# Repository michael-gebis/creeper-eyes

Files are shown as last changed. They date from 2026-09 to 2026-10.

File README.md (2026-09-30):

# Frankenstein Head with Animated Eyes

Twin animated eyes for Jose Aveleira's 3D-printed
[Frankenstein head with animated eyes](https://www.printables.com/model/620191-frankenstein-head-with-animated-eyes),
driven by an ESP32 and two 1.5" OLED panels.

The eyes wander, blink and dilate on their own, and keep doing it with nothing
plugged in but power. Everything past that is optional.

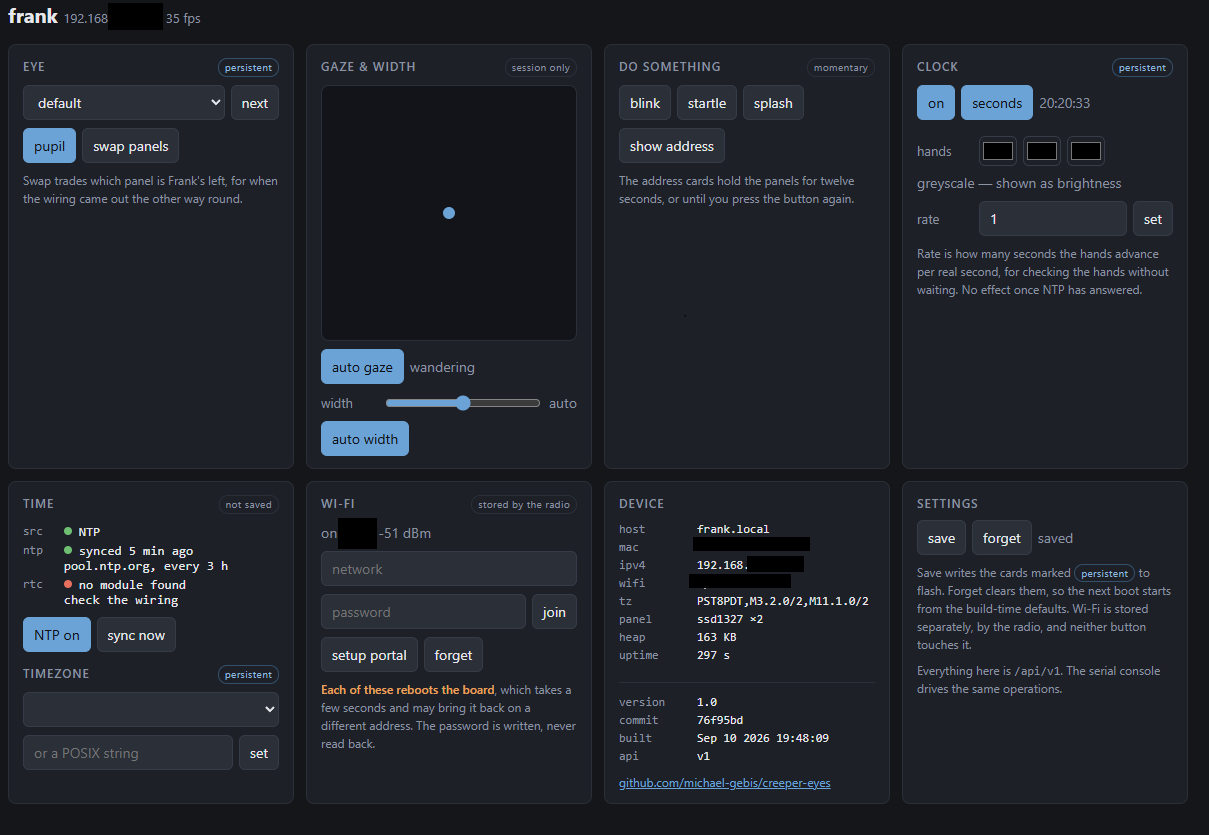
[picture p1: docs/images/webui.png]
The control page


## What it does

- **Twenty-five eye designs** — [see them all](docs/EYES.md). One is built in; any other can be
  loaded from a file on the control page, [no rebuild needed](docs/EYE_FILES.md)
- **Watches the room on its own**: wandering gaze, autonomous blinking, pupils
  that dilate
- **Takes direction** from a web page, a serial console or a REST API, so you
  can aim the gaze or fire a startle effect without opening the head
- **Tells the time**, with an analogue clock drawn in the iris
- **Sleeps at night**, so it is not staring at 3am
- **Dims to suit the room**, fading between levels, and switches right off —
  [brightness](docs/BRIGHTNESS.md)
- **Sets itself up from a code on the eye** — point a phone at it and it
  joins the head's network and opens the setup page, with nothing typed
- **Updates over WiFi**, so a sealed head never needs opening again
- **Runs on a generic ESP32** and either colour or greyscale panels

Two panels, one dev board, fourteen wires. If you would rather not have the
wires, there is [a circuit board](hardware/README.md) for it.

## What to buy

### ESP32 board

Any **classic ESP32** (ESP-WROOM-32 module, Xtensa dual core) with 4 MB flash.

> **Not** an ESP32-**S2**, **S3**, **C3** or **C6**. Those are different
> architectures and will not run this build. If your board shows up as USB
> vendor ID `303A`, it is one of those. A classic ESP32 uses a separate
> USB-serial chip — CH340 (`1A86`) or CP210x (`10C4`).

Known good: the 30-pin **DOIT ESP32 DevKit V1**, sold under a dozen names with
"NodeMCU", "ESP32S" and "Type-C" in the title. Roughly $5 each in three-packs.
Either USB-serial chip is fine; CH340 may need a driver on Windows.

### Displays — read this part carefully

Waveshare sells **two different 1.5" 128×128 OLED modules** with nearly
identical names and **identical 7-pin headers**. You cannot tell them apart by
wiring, and the wrong one shows white static.

| Product | Controller | Display | Build to use |
| :--- | :--- | :--- | :--- |
| **1.5inch RGB OLED Module** | SSD1351 | 65K colour | `esp32dev` |
| **1.5inch OLED Module** | SSD1327 | 16 greys | `gray` |

Buy **two**. Either works, and the grayscale panels run faster.

Which to get depends on the eyes you want. The artwork was drawn in colour,
and **some designs do not survive the conversion** — anything carrying its
detail in hue rather than in brightness comes out flat. The newt is the worst
of them: its greens and golds land on much the same grey. Others lose nothing
worth having; the default eye in particular looks every bit as good in
sixteen greys as it does in colour.

[docs/EYES.md](docs/EYES.md) renders all 25 designs both ways, side by side,
which is the quickest way to decide.

Both are 3.3 V / 5 V tolerant and need no level shifting.

### Everything else

- Breadboard and male-to-female jumper wires (14 connections)
- USB-C cable — this also carries the serial console
- The printed parts and hardware from the
  [Printables model](https://www.printables.com/model/620191-frankenstein-head-with-animated-eyes)

A plain USB port powers everything comfortably: two panels and the ESP32,
WiFi and all, sit well inside the 500 mA a port supplies.

## Wiring

Six signals are shared by both panels; only chip select differs. Left and
right below are **Frank's own**, so facing him, his right eye is the one on
your left.

| Signal | DevKit pin | Frank's right (your left) | Frank's left (your right) |
| :----- | :--- | :--- | :--- |
| VCC | `3V3` | VCC | VCC |
| GND | `GND` | GND | GND |
| DIN | `D18` | DIN | DIN |
| CLK | `D5` | CLK | CLK |
| DC | `D33` | DC  | DC  |
| RST | `D27` | RST | RST |
| CS | `D15` / `D4` | CS ← `D15` | CS ← `D4` |

> **Use `3V3`, never `VIN`.** ESP32 GPIOs are 3.3 V and not 5 V tolerant.

Module silkscreens vary between sellers — `DIN` may be labelled `SDA`, `SI` or
`MOSI`; `CLK` may be `SCL`, `SCK` or `D0`. Match by position, not by letters.

**Full details, assembly order and troubleshooting: [docs/WIRING.md](docs/WIRING.md).**

Optional, and compiled out by default: a **battery-backed clock**, four more
wires onto two otherwise idle pins — [docs/WIRING_RTC.md](docs/WIRING_RTC.md).

### Or a circuit board instead of the jumpers

The same fourteen wires exist as a carrier board in
[hardware/](hardware/README.md): the DevKit plugs into a socket, each eye gets
its own header, and the SPI bus is copper rather than Dupont leads — which
matters mostly because nothing can work loose inside a sealed head. About $10
for five boards.

> **Rev A is tested and works**: a DevKit on one drives two colour panels and a
> DS3231, the clock on jumpers because its header suits a different module
> from the one in use. **Rev B**, which changes that header, is **untested**:
> it passes KiCad's checks, and no board has been made.

## Build and flash

This is a [PlatformIO](https://platformio.org/) project. No Arduino IDE needed,
and nothing to install by hand beyond PlatformIO itself — the Xtensa toolchain,
the ESP32 Arduino core and the Adafruit libraries all download on the first
build.

**New to PlatformIO?** Install the
[PlatformIO IDE extension for VS Code](https://docs.platformio.org/en/latest/integration/ide/vscode.html).
It is the same two steps on Windows, macOS and Linux — install VS Code, then
install the extension — and its Quick Start walks you through building a
blinking LED before you come back here. The extension includes the command
line this page uses, so nothing below is closed off by starting there.

**Happier in a terminal?** Install PlatformIO Core on its own. The
[installation methods](https://docs.platformio.org/en/latest/core/installation/methods/index.html)
page covers all three systems; the short version is:

```sh
uv tool install platformio       # or: pipx install platformio
```

### Environments

| Environment | Builds | Use for |
| :--- | :----- | :--- |
| `esp32dev` | Eyes, SSD1351 colour | **Default.** Waveshare 1.5inch RGB OLED |
| `gray` | Eyes, SSD1327 grayscale | Waveshare 1.5inch OLED |
| `displaytest` | Solid-colour fills, SSD1351 | Bring-up and fault isolation |
| `probe1327` | Raw SSD1327 init, no library | Identifying an unknown panel |
| `esp32dev_rtc` / `gray_rtc_open` | Eyes plus a battery-backed clock | With a [DS3231 fitted](docs/WIRING_RTC.md) |
| `gray_rtc` | The same, with authentication on | A head left on a network. Needs credentials in `secrets.h` |
| `esp32dev_local` / `gray_local` | Eyes only, no networking | A head with no WiFi — about 695 KB smaller |
| `gray_rtc_ota` / `esp32dev_rtc_ota` | The RTC builds, flashed over WiFi | **Use these** to update an RTC or authenticated head |
| `esp32dev_ota` / `gray_ota` | The plain builds, flashed over WiFi | Updating a sealed head. Using one on an RTC board flashes the RTC and auth away |
| `rtc_probe` | Raw I²C scan and DS3231 read | Bringing up an RTC module |
| `qrtest` / `qrtest_rgb` | QR codes on the panels, grey / colour, no network | Measuring what a phone can read — [Codes on the eyes](docs/QR.md) |

`gray_rtc` is the only environment that requires anything of you before it
will build: `AUTH_USER`, `AUTH_PASS`, `AUTH_TOKEN_VALUE` and `OTA_PASSWORD` in
`include/secrets.h`. It stops with an error naming them rather than producing
an open device. Use `gray_rtc_open` to skip that.

### Commands

```sh
pio run                              # build the default (colour) environment
pio run -e gray -t upload            # build and flash the grayscale build
pio run -e gray -t upload -t monitor # ...and open the console
pio device monitor                   # console only
pio device list                      # find the serial port
```

If the port is picked wrongly, pin it in `platformio.ini` with
`upload_port = COM5` (or `/dev/ttyUSB0`).

## Where to go next

This page gets you a working head. Everything else has a page of its own.

| | |
| :-- | :-- |
| [Wiring](docs/WIRING.md) | Every wire, in order, with what goes wrong |
| [The eyes](docs/EYES.md) | The gallery, choosing designs, the pupil, the startup cards, a panel fitted the wrong way |
| [Eye files](docs/EYE_FILES.md) | One more design, loaded from the control page without a rebuild |
| [Driving it](docs/CONTROL.md) | Web page, serial console, REST API |
| [Networking](docs/NETWORK.md) | Joining WiFi, changing it later, updating over the air |
| [Codes on the eyes](docs/QR.md) | Setup and address codes, and what a phone can really read off a panel |
| [Keeping time](docs/TIME.md) | Time servers, the clock face, running without a network |
| [Brightness](docs/BRIGHTNESS.md) | The dimmer: curves, fades, matching two panels |
| [Sleep mode](docs/SLEEP.md) | Dark panels overnight |
| [Configuring](docs/CONFIG.md) | Every build option, and what gets saved |
| [Locking it down](docs/SECURITY.md) | Passwords, and why there is no HTTPS |
| [A circuit board](hardware/README.md) | The wiring as a PCB — rev A tested, rev B not yet made |
| [Testing](docs/TESTING.md) | The test suite, the soak harness, the tools |
| [Frame rate](docs/FRAME_RATE.md) | How the eyes went from 19 frames a second to 51 on colour, and from 33 to 75 on greyscale |

And two pages that are neither instructions nor reference, but a record of
being wrong in public: [why a 35-byte request took 50 ms](docs/HTTP_LATENCY.md)
and [the battery-backed clock](docs/WIRING_RTC.md).

## Troubleshooting

| Symptom | Cause |
| :--- | :---- |
| **Both panels show white static** | Wrong controller. You have SSD1327 panels and built `esp32dev`, or vice versa. Confirm with `pio run -e probe1327 -t upload -t monitor` — if the panels respond to that, they are SSD1327; build `gray`. |
| Both panels dark | Power, or `D27` (RST) not connected. Check 3V3 and GND at the module pins. |
| One panel dark | That panel's `CS` wire. Everything else is shared, so a shared fault would take out both. |
| Flicker or speckle | Bus integrity. Shorten the `CLK` and `DIN` jumpers, or lower the bus speed: `SSD1351_SPI_HZ` for colour, `SSD1327_SPI_HZ` for greyscale. |
| Garbled serial output | `DEBUG_BAUD` and `monitor_speed` disagree, or a CH340 clone struggling above 115200. |
| Board resets when a panel is connected | Brownout. Use a powered hub or feed 5 V to `VIN`. |
| Board will not boot | Something on `D12`. Held high at reset it stops the ESP32 starting. No eye signal uses it. |
| The web page lags, or an update fails | Almost certainly the radio. Check the signal on the Wi-Fi card — the page says what the number means. Every delay and every failed update measured on this project traced back to packet loss, not to the firmware. `uv run tools/test_api.py --host frank.local --decompose 200` takes the guesswork out of it. |

Frame rate is **not** a useful signal for whether panels are connected — the
SPI writes happen either way, so the rate is the same with nothing attached.

For bring-up, `displaytest` drives each panel alone with solid fills at a
deliberately slow 2 MHz, which separates wiring faults from rendering faults.

## Credits

**The head itself is [Jose Aveleira's](https://www.printables.com/@JoseAveleira_1373378)**
— [Frankenstein head with animated eyes](https://www.printables.com/model/620191-frankenstein-head-with-animated-eyes)
on Printables. None of this has anywhere to live without it.

Firmware lineage, oldest first:

- **[Adafruit Uncanny Eyes](https://learn.adafruit.com/animated-electronic-eyes)** — Phil Burgess / Paint Your Dragon, for Adafruit Industries. The rendering engine and the eye artwork. SPI FIFO insight from Paul Stoffregen's `ILI9341_t3`; concept inspired by David Boccabella (Marcwolf).
- **Laurent Moll**, 2018 — [Uncanny Eyes costume](https://www.hackster.io/projects/376a13/), dual-display ESP32 work.
- **[bitcldr/creeper-eyes](https://github.com/bitcldr/creeper-eyes)** — the PlatformIO project this forks from.
- **[TeensyEyes](https://github.com/chrismiller/TeensyEyes)** — Chris Miller. MIT. 23 of the 25 eye designs are converted from its artwork by [`tools/gen_eyes.py`](tools/gen_eyes.py).
- This fork — generic ESP32 support, grayscale panels, console, splash, diagnostics,
  networking, the control page and API, eye files, the dimmer and the carrier board.

Three bugs fixed here also affect the upstream colour build: an out-of-range
eyelid index that put a teardrop artifact at one eye's edge, a shared reset
line that wiped the first panel's initialisation while the second started, and
a chip-select constant that selected the wrong panel during init.

MIT licensed — see [LICENSE](LICENSE).

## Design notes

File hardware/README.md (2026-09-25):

# A circuit board for Frank

The breadboard and its fourteen jumper wires, as a printed circuit board: a
carrier that the ESP32 DevKit plugs into, with a header for each eye and one
for the optional clock, and the SPI bus in copper instead of Dupont leads.

> **Rev A is tested and works.** A DevKit plugged into one drives two colour
> panels, with a DS3231 on jumpers — its header suits the ZS-042, not the
> module in use, which is what rev B changes — and without C1. Under long,
> heavy test load on a single USB-C supply it browned out now and then; see
> [Frame rate](../docs/FRAME_RATE.md#brownouts-and-the-cpu-at-160-mhz). Fit C1.
>
> **Rev B is untested.** It passes KiCad's checks — electrical rules,
> schematic against board, design rules — and no board has been made.

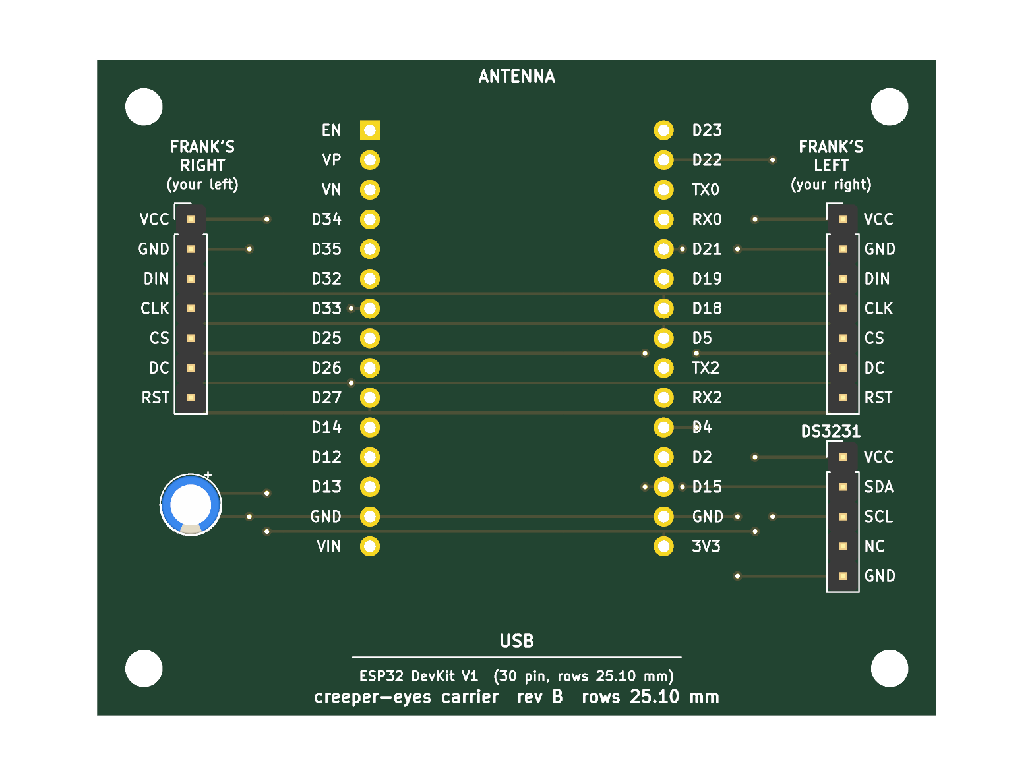
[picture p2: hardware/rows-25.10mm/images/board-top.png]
The board, top side


## What it is

There are no discrete electronics in this project. The whole thing is three
off-the-shelf modules and the wires between them:

- an ESP32 DevKit V1 (30-pin, 2.54 mm headers)
- two Waveshare 1.5" OLED panels, which share an identical 7-pin header
- optionally, a DS3231 module

So the board is a **carrier**: a socket for the DevKit, a 7-pin header for
each eye, a 5-pin header for the RTC, and the shared SPI bus routed between
them in copper. One capacitor, because the panels' boost converters draw in
bursts and it costs nothing. No active parts, nothing surface-mount, nothing
to calculate. Its job is to replace the breadboard with something that cannot
come loose inside a sealed head.

The wiring is exactly [WIRING.md](../docs/WIRING.md) and
[WIRING_RTC.md](../docs/WIRING_RTC.md):

| Signal | DevKit pin | Goes to |
| :----- | :--- | :--- |
| 3V3 | `3V3` | both panels, RTC, C1 |
| GND | `GND` | both panels, RTC, C1 |
| DIN | `D18` | both panels |
| CLK | `D5` | both panels |
| DC | `D33` | both panels |
| RST | `D27` | both panels |
| CS | `D15` | Frank's right panel (J3, your left) |
| CS | `D4` | Frank's left panel (J4, your right) |
| SDA | `D21` | RTC |
| SCL | `D22` | RTC |

72 × 56 mm, two layers, four M3 mounting holes. The DevKit plugs in with its
USB connector towards the bottom edge and its antenna end flush with the top
edge — the antenna section overhangs by about half a millimetre, and there
is no copper anywhere near it in any case. Every socket pin is labelled with the
DevKit's own name for it, and each eye connector says whose eye it is in
both senses, so a board sitting on the bench answers the question the wiring
guide spends a page on.

The panels connect by cable — a 7-wire Dupont lead or a JST-XH pigtail onto
each header — because they live in the head's eye sockets, not on the board.
The RTC header takes the five-pin "DS3231 mini" module sold for the Raspberry
Pi, which plugs straight onto it: `VCC SDA SCL NC GND` from top to bottom,
matching the module's own `+ D C NC -`, with GND on the bottom pin. Any other
module goes on by four wires to the labelled pins.

## Revisions

**Rev B**, current, untested: J5, the RTC header, is five pins in the order of the
DS3231 mini module (`VCC SDA SCL NC GND`, rows 12–16) instead of six in the
ZS-042's (`32K SQW SCL SDA VCC GND`, rows 12–17). SCL keeps its route; SDA,
VCC and GND each come in on a different row. Nothing else moved.

**Rev A**, the first order, tested and working: the mini module does not plug
onto J5. Wire it
by name instead — four jumpers, module `+`→`VCC`, `D`→`SDA`, `C`→`SCL`,
`-`→`GND` — and leave J5's `32K` and `SQW` empty. Power off first: the
firmware only looks for the RTC at boot.

## What it costs

| | Five boards | Per board |
| :-- | :-- | :-- |
| JLCPCB or PCBWay, 2-layer, 72 × 56 mm | ~$2 fabrication, $2–5 slow shipping (~$20 by courier if impatient) | under $2 |
| Two 1×15 female headers, 2.54 mm — the DevKit socket | ~$1 | |
| Two 1×7 and one 1×5 male pin headers, 2.54 mm | ~$1 | |
| C1, electrolytic, 5 mm diameter, 2 mm lead pitch: 10 µF works, but take the largest that comes in a 5 mm can, typically 22 or 47 µF | pennies | |

**About $10 for five boards, all in**, and one to two weeks. The DevKit and
the displays you already own plug into it.

The other tier — an integrated board with the ESP32-WROOM module soldered
down, USB-C, a CH340 and a regulator, assembled at the fab — comes to $8–15 a
board in small quantities plus setup fees, and buys nothing over the $5 DevKit
except a slimmer profile and the loss of "unplug it and swap it". Not worth
it. This is a carrier board.

## Two boards, because there are two DevKits

Along each row the pins are on 2.54 mm centres on every board — that is the
header strip itself, and nobody gets it wrong. The distance *between* the two
rows is the clone maker's own choice, and it varies. So the design is one and
the boards are two, in directories named for the number:

| Directory | Row pitch | For |
| :-- | :-- | :-- |
| `rows-25.10mm/` | 25.10 mm | The author's DevKit, a 30-pin "DevKit V1" clone, measured |
| `rows-25.4mm/` | 25.4 mm (1.0") | The DOIT reference design and clones that follow it |

Each holds its own KiCad project, a `gerbers/creeper-eyes-rows-…-gerbers.zip`
to upload, and renders. The pitch is printed on both sides of the board, so
five of each can sit in a drawer without confusion.

## Before ordering: two things to check against your DevKit

Both are things a datasheet cannot settle, because "ESP32 DevKit V1" is a
name a dozen factories use.

1. **The row pitch.** Measure across both rows of pins with calipers, at
   the base of the pins where they enter the plastic rather than at the
   tips, which are often toed in. Take the outside-to-outside and the
   inside-to-inside readings: their average is the centre-to-centre pitch,
   and their difference should be one pin width (~0.64 mm), which tells you
   the measurement is sound. The author's board read 25.72 and 24.48, so
   25.10. Order the variant that matches; if neither does, add a line to
   `VARIANTS` in `gen_board.py` and regenerate (below). Half the board moves
   with it; nothing needs redrawing.
2. **The pinout.** Hold the DevKit with the USB connector towards you,
   components up. The left row should read `EN VP VN D34 D35 D32 D33 D25 D26
   D27 D14 D12 D13 GND VIN` top to bottom, and the right row `D23 D22 TX0 RX0
   D21 D19 D18 D5 TX2 RX2 D4 D2 D15 GND 3V3`. That is what the board's
   silkscreen says beside each socket pin, so a mismatch is a matter of
   holding the two next to each other. If a pin differs, `DEVKIT_LEFT` and
   `DEVKIT_RIGHT` in `gen_board.py` are where to say so.

Then two things worth knowing that are not risks: the pads are square for
pin 1 of every connector, and C1's footprint carries a `+` mark on the
silkscreen — the longer lead of the capacitor goes there.

## Ordering

Upload the zip from the matching variant's `gerbers/` directory to
[JLCPCB](https://jlcpcb.com) or [PCBWay](https://www.pcbway.com). The defaults are right: 2 layers, 1.6 mm,
HASL, any colour, quantity 5. Nothing on the board comes near a design rule —
the narrowest anything gets is 0.25 mm tracks and about 0.3 mm of clearance,
against minimums of 0.127.

Solder the two 15-pin sockets first, using the DevKit itself as a jig to keep
them parallel: plug the sockets onto the DevKit, drop the assembly into the
board, solder, unplug. Then the pin headers, then C1.

## How it was made, and how to change it

The board is generated by a script rather than drawn, because the one
dimension that has to be measured moves half the layout.

Both scripts run with the Python *inside* KiCad, not the system one, because
the layout is built through KiCad's own `pcbnew` module. Where that lives:

| | |
| :-- | :-- |
| Windows | `%LOCALAPPDATA%\Programs\KiCad\<version>\bin\python.exe` |
| macOS | `/Applications/KiCad/KiCad.app/Contents/Frameworks/Python.framework/Versions/Current/bin/python3` |
| Linux | the system `python3`, with KiCad's packages installed |

```sh
"$KICAD_PYTHON" hardware/gen_board.py     # writes every variant
"$KICAD_PYTHON" hardware/make_outputs.py  # checks and exports each
```

Either takes a pitch as an argument to do just one: `gen_board.py 25.4`.

Needs [KiCad](https://www.kicad.org/) 9 or later — the author used 10.
`gen_board.py` holds the netlist as one table and the routing as a list of
coordinates on a 2.54 mm grid, with everything right of the DevKit's left row
placed relative to the pitch; `make_outputs.py` runs the electrical rule
check, compares the schematic's netlist with the board's pad by pad, runs the
design rule check with schematic parity, and only then exports the Gerbers
and the renders. All three pass clean for both variants at the moment.

Editing in KiCad directly also works — it is an ordinary project — but a
regeneration will overwrite it, so a change worth keeping belongs in the
script.

The DevKit's footprint and the three symbols with meaningful pin names live in
each variant's `.pretty/` directory and `.kicad_sym` file, which its library
tables point at.

## Not on the board

Kept off deliberately, and cheap to add if there is ever a reason:

- a header breaking out the unused pins (`D23`, `D25`, `D26`, `D32`, `D34`,
  `D35`, …) for sensors. Not `D19`: the firmware hands it to the SPI
  peripheral as MISO in `SPI.begin(SCLK_PIN, MISO_PIN, MOSI_PIN)`, and
  although nothing is ever read back — the panels are write-only — the
  peripheral is attached to the pin all the same. Passing `-1` there instead
  would genuinely free it, and is the change to make before breaking it out.
- a photocell, which upstream Uncanny Eyes uses to drive dilation. A light
  sensor for the [dimmer](../docs/BRIGHTNESS.md) is on the
  [TODO list](../TODO.md#a-light-sensor-for-automatic-brightness), and the
  unused `D34`, `D35`, `VP` and `VN` are where it would go
- a ground pour — at 8 MHz on a 7 cm board, with the breadboard already
  working, it would be decoration

## Files

| | |
| :-- | :-- |
| `gen_board.py` | The design, as a script. Edit this. |
| `make_outputs.py` | Checks, Gerbers, renders |
| `rows-25.10mm/`, `rows-25.4mm/` | One directory per DevKit row pitch, each containing: |
| `  creeper-eyes-rows-…mm.kicad_pro` / `.kicad_sch` / `.kicad_pcb` | The KiCad project the script writes |
| `  creeper-eyes-rows-…mm.pretty/`, `.kicad_sym` | Project footprint and symbol libraries |
| `  gerbers/creeper-eyes-rows-…mm-gerbers.zip` | What the fab wants |
| `  images/` | Renders of both sides, and the schematic as a PDF |

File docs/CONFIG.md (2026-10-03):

# Configuring the firmware

Two kinds of setting, and it matters which is which.

**Build options** are compile-time: they decide what is in the firmware at
all, and changing one means a rebuild. Every switch is `#ifndef`-guarded, so
it can be overridden from `platformio.ini` without editing a header — with the
exception of the pin numbers, noted below.

**Saved settings** are runtime: the eye design, the timezone, the clock
colours. They live in flash, survive a reboot, and are changed from the
control page or the console.

## Build options

Compile-time switches. Most live in [`src/config.h`](../src/config.h); the ones
inherited from upstream are still declared in `src/main.cpp`, next to the
rendering code they belong to. Either way each is `#ifndef`-guarded, so any of
them can be overridden from `build_flags` in `platformio.ini` without editing
a source file — which is how the `gray` environment sets `USE_SSD1327`.

A few settings are PlatformIO's rather than the firmware's, and live in
`platformio.ini` itself, commented there: the partition table
(`board_build.partitions`, see [Eye files](EYE_FILES.md#where-the-room-came-from)),
and the flash at 80 MHz on four data lines (`board_build.f_flash`,
`board_build.flash_mode`) instead of the board definition's 40 MHz on two, which
roughly halved the time to draw an eye. Both only reach a board by a USB flash:
the partition table is written only by one, and the flash speed is set by the
bootloader, which is too. The CPU runs at 160 MHz rather than 240
(`board_build.f_cpu`), which saves enough current to matter. With
`OVERLAP_SEND` colour frames wait on the SPI bus, not the CPU, so it costs them
two frames a second; greyscale frames wait on the drawing and pay more, about a
quarter — see [Frame rate](FRAME_RATE.md#brownouts-and-the-cpu-at-160-mhz).
That is only the speed a board starts at: one with the supply for it can be
set to 240 without a rebuild, and keeps it as a
[saved setting](#remembering-settings).

Two groups are **not** guarded and cannot be overridden this way. A few
names are not settings at all: `CONTROLLABLE`, `OTA_AUTH` and
`FIRMWARE_COMMIT` are computed from others, `DIM_GAMMA_MIN` and
`DIM_GAMMA_MAX` are fixed limits, and `FAVICON_FRANK` and `FAVICON_EYES` are
the two values `FAVICON` chooses between. And the **pin numbers** in
[`src/main.cpp`](../src/main.cpp) (`DISPLAY_DC`, `DISPLAY_RESET`,
`SELECT_L_PIN`, `SELECT_R_PIN`, `MOSI_PIN`, `MISO_PIN`, `SCLK_PIN`) are plain
`#define`s: `-DDISPLAY_DC=…` is a macro
redefinition, not an override, so those are edited in place. They are wiring,
not preference — change them only if you wire differently, and update
[docs/WIRING.md](WIRING.md) to match.

| Option | Default | Effect |
| :----- | :--- | :----- |
| `USE_SSD1327` | `0` | Selects the grayscale panel driver. Set by the `gray` environment via `build_flags`, not edited by hand. |
| `COMMANDS` | `1` | Serial console and BOOT-button toggle. `0` compiles both out; the REST API still works, so a network build stays fully controllable. |
| `DEBUG` | `1` | Serial diagnostics and the LED heartbeat, which toggles once a second. `0` saves ~2 KB. |
| `DEBUG_BAUD` | `115200` | Console speed. **Must match `monitor_speed`** in `platformio.ini`. |
| `DEBUG_LED_PIN` | `2` | On-board LED used for the heartbeat. |
| `STARTUP_SPLASH` | `1` | Panel name cards at boot. `0` boots straight into the eyes. |
| `SPLASH_SECONDS` | `5` | How long the splash counts down. |
| `BOOT_BUTTON_PIN` | `0` | Button that cycles eye designs; held, the factory reset. |
| `SSD1327_SPI_HZ` | `8000000` | Grayscale bus speed. Lower it if long jumpers cause flicker. |
| `SSD1351_SPI_HZ` | `16000000` | Colour bus speed. A colour frame is four times the data of a greyscale one, so sending an eye is most of a colour frame: 33 ms at the library's 8 MHz, 18 ms at 16. The SSD1351 is rated to 20 MHz, which speckled one panel on the carrier board. Lower it if long jumpers speckle the image. |
| `RAM_TABLES` | `1` | Keep the current design's polar map and iris, 45 KB, in RAM rather than flash. Drawing reads both out of order, so from flash they miss the cache: an eye took 6.2 ms to draw from flash and 4.5 ms from RAM. `0` gives the RAM back. |
| `OVERLAP_SEND` | `1` | Send each eye's frame from the ESP32's other core while the render loop draws the next, so a frame takes as long as the longer of the two instead of both together: 41 fps to 53 on colour, and 55 to 101 on greyscale, both at 240 MHz. At the default 160 MHz they come to 51 and 75. Costs a second frame buffer, 32 KB on colour and 8 KB on greyscale. See [Frame rate](FRAME_RATE.md). |
| `STARTLE_WINDUP_MS` | `1400` | Slow constrict before the startle jolt. |
| `CLOCK` | `1` | Analogue clock face. `0` compiles it out. |
| `CLOCK_*_LEN` / `CLOCK_*_HW` | — | Hand lengths and half-widths, in pixels from the iris centre. |
| `CLOCK_*_COLOR` | `0x000000` | Starting hand colours, changeable at runtime with `clock color`. |
| `CLOCK_NOON` | `128` | Where twelve sits, in the polar table's 0–511 angle. |
| `PUPIL_OFF_SCALE` | `64` | Iris scale used when the pupil is off. At or below 64 the pupil vanishes. |
| `NETWORK` | `1` | WiFi, NTP, web server and OTA. `0` compiles all of it out: about 695 KB, taking `esp32dev` from 65% of the 1.81 MB app partition to 27%. |
| `RTC` | `0` | A DS3231 battery-backed clock. `1` fits one; costs ~26 KB. See [docs/WIRING_RTC.md](WIRING_RTC.md). |
| `RTC_SDA_PIN` / `RTC_SCL_PIN` | `21` / `22` | I²C pins for it. Both otherwise unused. |
| `RTC_ADDR` | `0x68` | The DS3231's fixed address. |
| `FAVICON` | `FAVICON_FRANK` | Tab icon. `FAVICON_EYES` is a generic alternative for a build that is not going into a Frankenstein. |
| `OTA_REBOOT_DELAY_MS` | `1500` | How long after a successful update the board waits before rebooting into it, so the sender hears that it worked. `0` restores the library's behaviour. |
| `OTA_TIMEOUT_MS` | `10000` | How long the board waits for the next block of an over-the-air update. The core's 1000 is shorter than the sender's patience. |
| `AUTH_HTTP` | `0` | Digest authentication on the page, the API and `/cmd`. Needs `OTA_PASSWORD` as well. Either this or `AUTH_TOKEN` also turns on the refusal of requests another site sent — see [Locking it down](SECURITY.md#the-web-interface). |
| `AUTH_TOKEN` | `0` | A bearer token as an alternative credential, for scripts. Needs `OTA_PASSWORD` as well. |
| `AUTH_HOST_CHECK` | `0` | Refuse requests whose `Host` is not this device — the DNS-rebinding defence. |
| `AUTH_NONCE_S` | `300` | How long one digest nonce lasts. Past it, a browser is told its nonce is stale and retries without asking for the password — see [Locking it down](SECURITY.md#the-web-interface). |
| `SLEEP` | `1` | Dark panels overnight. `0` compiles it out. |
| `SLEEP_ENABLED` | `0` | Whether the window is in force out of the box. Off: a prop going dark unasked reads as a fault. |
| `SLEEP_START_MIN` / `SLEEP_STOP_MIN` | `22*60` / `7*60` | The default window, in local minutes past midnight. |
| `SLEEP_LEVEL` | `0` | 0 switches the panels off and stops rendering; 1–100 is that share of the brightness setting, and the eyes keep moving. |
| `SLEEP_WAKE_S` | `60` | How long a command holds the eyes awake inside the window. `0` makes the window absolute. |
| `DIM_GAMMA_X10` | `22` | The default brightness curve, in tenths: 22 is gamma 2.2, 10 is linear. Changeable at runtime — see [Brightness](BRIGHTNESS.md). |
| `DIM_FADE_MS` | `500` | How long a brightness fade across the whole range takes. |
| `DIM_SWEEP_MS` | `8000` | Each half of `dim sweep`. |
| `FACTORY_RESET_MS` | `10000` | How long BOOT must be held, while running, to erase every setting and stored credential — not the WiFi network, nor the eye slot. `0` removes the gesture, and so does `COMMANDS=0`, which is what polls the button. |
| `IPV6` | `0` | All of IPv6, compiled out. Cannot usefully be turned on yet — see [IPv6](NETWORK.md#ipv6). |
| `FIRMWARE_VERSION` | `1.0` | Bumped by hand, for features worth announcing. |
| `PROJECT_URL` | this repository | Shown by `version` and on the control page. |
| `WEB_CMD_ENDPOINT` | `1` | The `/cmd` escape hatch. `0` leaves only the REST API. Needs `COMMANDS`, since it is a passthrough to the console. |
| `REQUEST_HEAD_MAX` / `REQUEST_BODY_MAX` | `3072` / `2048` | The largest request head, and body (the streamed eye file aside), the web server takes. Anything larger is refused with `431` or `413` before any of it is read. Together they must fit the TCP window, 5760 bytes, or an allowed request could never arrive whole — see [Driving it](CONTROL.md#web-interface). |
| `REQUEST_ARRIVE_MS` | `5000` | How long a request has to arrive in full. It waits outside the render loop meanwhile, and is dropped after this. |
| `WIFI_HOSTNAME` | `frank` | DHCP and mDNS name, and the name the control page and the console's `version` give the board. |
| `WIFI_AP_NAME` | `frank-setup` | The setup portal's own network name. |
| `QR_CODES` | `NETWORK` | Codes on the panels: one that joins the setup network, one that opens the control page. `0` leaves plain text — see [Codes on the eyes](QR.md). |
| `PORTAL_PASSWORD` | `QR_CODES` | A random password on the setup network, which is only reasonable because the panels can show it. Follows `QR_CODES`, and `0` leaves the portal open. |
| `NTP_SERVER_1` / `NTP_SERVER_2` | `pool.ntp.org`, `time.nist.gov` | Time servers. A server on your own LAN works here. |
| `NET_SHOW_MS` | `12000` | How long `net` leaves the address cards up. |
| `NET_COLS` | `21` | Characters a 128 px panel fits, for wrapping those cards. |
| `TZ_MAX` | `48` | Longest POSIX timezone string that can be stored. |
| `WIFI_CONNECT_MS` | `15000` | How long to wait on a known network before opening the portal. |
| `WIFI_PORTAL_S` | `60` | How long the portal stays up before carrying on offline. |
| `WIFI_RETRY_MS` | `30000` | How often to try again after giving up at boot. |
| `TZ_DEFAULT` | US Pacific | Timezone before one is saved. |
| `STARTLE_HOLD_MS` | `1200` | How long the eyes stay wide afterwards. |

Inherited from upstream, unchanged:

| Option | Default | Effect |
| :----- | :--- | :----- |
| `TRACKING` | on | Eyelids follow the pupil. |
| `AUTOBLINK` | on | Eyes blink on their own. |
| `IRIS_MIN` / `IRIS_MAX` | `150` / `400` | Pupil range: `IRIS_MIN` is the narrowest pupil and `IRIS_MAX` the widest. |

One switch is derived rather than set: `CONTROLLABLE` is `COMMANDS || NETWORK`,
and gates the machinery both interfaces share — the operations layer in
[`src/state.h`](../src/state.h), the settings it persists, and the state the
renderer reads. Turning off *both* interfaces leaves the eyes running on their
own with nothing able to change them, which builds and works but is only
useful if you want a prop with no controls at all.

## Remembering settings

Settings can be stored in NVS, so a sealed head comes back the way you left
it:

```
> eye dragon
> swap on
> pupil off
> save
ok saved eye=dragon swap=on
```

| Saved | Not saved |
| :---- | :--- |
| Eye design | The clock's time |
| Panel swap and flip | Gaze (`look`) |
| Brightness, its curve, and each panel's trim | A brightness sweep |
| Pupil on/off | Dilation (`dilate`) |
| Clock on/off, rate, second hand, hand colours | |
| Timezone | |
| Time server on or off (`ntp on` / `ntp off`) | |
| Sleep: enabled, window, level | |

Wi-Fi credentials are the exception to all of this: they are stored by the
radio in its own part of NVS, not by `save`, and `forget` does not clear
them. `wifi forget` does. The control page says the same thing on each card,
so you never have to come back here to find out what a control will do.

The **CPU speed** is stored differently too. `cpu 240`, the buttons on the
control page and `PUT /api/v1/cpu` store it at once rather than waiting for
`save`, because it only takes effect when the board restarts, so there is
nothing to try out first. `forget` clears it with everything else, and the
build's speed applies again from the next boot.

Gaze and dilation are deliberately transient — they are things you drive,
not things you configure.

The clock's **time** is excluded on purpose. A time saved at power-off comes
back wrong by exactly the interval the device was off, and the plan is to
take the time from NTP, which makes a stored one pointless as well as
misleading. Its display preferences are saved; only the time is not, so
`clock set` is the one clock command that does not mark settings unsaved.

**`forget` also clears any stored credentials**, since they share this
namespace — see [Locking it down](SECURITY.md#forget-does-this-too-and-it-is-reachable-over-the-network).

`status` marks unsaved changes with `(unsaved)`. `forget` clears the stored
settings and the build defaults apply again at the next boot.

Saving is explicit rather than automatic: NVS writes have finite endurance,
and the BOOT button cycles eye designs, so auto-saving would write flash on
every press.

The design is stored **by name**, not by index. Indices shift whenever the set
of `EYE_*` switches changes, so a saved index could silently select a
different design after a rebuild. If a saved design is not on the board,
it falls back to the first one and says so, as below.

### If stored settings are damaged

Nothing read back from flash is trusted. NVS already checks a CRC on every
entry, so a torn write or a flipped bit reads as a missing setting, and the
built-in default applies. What it cannot catch is a value that is intact but
wrong: saved by an older firmware, restored from another board's backup, or
written by hand. So each setting is checked as it is loaded:

- **The type.** A key saved as a string where a number belongs is not that
  number.
- **The range.** A clock rate must be 1–3600, a sleep time a real minute of
  the day, a colour 24 bits, and so on. These are the same limits the console
  and the API enforce when you set them.
- **The length and the characters**, for strings. Each is read into a
  fixed-size buffer and never anywhere larger. A timezone must look like a
  POSIX TZ string, a password must pass the rules for setting one, and the OTA
  hash must be 32 hex digits.

A value that fails is **ignored**, the default is used, and the bad copy is
**removed**, so the next boot starts clean. The WiFi network the radio keeps is
checked too. One with control characters in it could never be joined, so it is
forgotten, which sends the board to the setup portal where a good one replaces
it. A damaged [eye file](EYE_FILES.md) in the slot is cleared. An RTC whose
registers hold an impossible date is treated like one whose battery ran out:
its time is ignored until the next time the clock is set, which overwrites it.

Each of these is **reported**, not just handled. The control page shows a box
above the cards listing what was found and what was done. The console has the
same list under `warnings`, and `GET /api/v1/state` carries it as
`system.warnings`. The list lasts until the next restart.

```
> warnings
  stored clkRate is 0, outside 1-3600; reset to the default
  the stored WiFi network was damaged and has been forgotten
```

The same list reports a restart the board did not plan: after a crash, a
watchdog or a brownout, it says so at the next boot, rather than leaving the
reason in serial output nobody was watching. It says which watchdog, and for
the task watchdog — which fires when core 0 has been kept too busy for five
seconds — which task had been keeping it busy. A brownout means the supply sagged
too far — see [Frame rate](FRAME_RATE.md#brownouts-and-the-cpu-at-160-mhz).
Power-on, the reset button and restarts the firmware asks for, for an update, a
WiFi change or the `restart` command, stay quiet.

A board set to 240 MHz that browns out comes back at 160, stores that, and
says so in the same list, so a head sealed in a prop browns out once rather
than every time it is switched on:

```
> warnings
  the board restarted after a brownout: the supply dipped too low
  dropped to 160 MHz after the brownout; set 240 again to retry
```

And it reports a speed-up that could not be set up for want of memory: the
task that sends frames from the other core (`OVERLAP_SEND`), or the copy of the
eye tables in RAM (`RAM_TABLES`). The eyes still run, drawn the slower way, so
without the warning the lower frame rate would look like the normal one.

```
> warnings
  the frame sender could not start; frames are slower
  no memory for the eye tables in RAM; frames are slower
```

A failed RAM copy is tried again at each change of eye design, and reported
only the first time.

A saved eye design that is simply not on the board is reported but *not*
removed. It may be a loaded design whose file is gone, and loading that file
again should bring the setting back.

## Versions

```
> version
frank 1.0 (41038d1), built Sep 10 2026 16:12:04
https://github.com/michael-gebis/creeper-eyes
```

The same three facts are on the control page, under Device, and at
`GET /api/v1/info`.

`FIRMWARE_VERSION` in [`src/config.h`](../src/config.h) is bumped by hand, and
only for something worth telling somebody about — the commit already
distinguishes every build. The commit comes from
[`tools/git_rev.py`](../tools/git_rev.py), which PlatformIO runs before each
build; outside a git checkout it reads `unknown`, and a build made with
uncommitted changes is marked `+dirty`, because an unmarked hash is a promise
that the binary *is* that commit.

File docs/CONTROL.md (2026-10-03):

# Driving the head

Three ways to take over from the autonomous motion, all reaching the same
operations underneath: a web page, a serial console, and a REST API. Anything
one can do, the others can too.

If you are not sure which you want: open `http://frank.local/` in a browser.

## Web interface

The control page

**http://frank.local/** — a control page for everything the console can do:
eye design (and [eye files](EYE_FILES.md)), gaze, dilation, pupil, panel swap and flip,
[brightness](BRIGHTNESS.md), clock and hand colours, the time and its sources, sleep,
passwords, Wi-Fi, the address details, the CPU speed and a restart button — and, above the cards, anything wrong
the board [found in its stored settings](CONFIG.md#if-stored-settings-are-damaged).
It polls the device once a second,
so two browsers looking at it stay in step with each other and with anything
you type over serial.

Each card says what happens to its settings when the power goes off —
persistent, session only, or momentary — because that is the first question
anyone asks of a control they have just moved.

The page is static: [`data/index.html`](../data/index.html), gzipped into the
firmware at build time by [`tools/gen_page.py`](../tools/gen_page.py) and served
straight out of flash. About 45 KB becomes 15; compressing it took the page
load from 554 ms to under 100 when that was measured — the board sends roughly one TCP segment per rendered frame, so
the only thing that really helps is sending fewer of them. Its tab icon is an inline SVG `data:` URI from
[`src/favicon.h`](../src/favicon.h) rather than a `/favicon.ico` route — no
second handler, and no second request against a server that manages one
client at a time. Two are bundled: Frank's head, and just the eyes for a
build going into something that is not a Frankenstein. Pick with `FAVICON`.
Its title is the board's own name, `WIFI_HOSTNAME`, which `gen_page.py`
fills in along with the icon. Everything on it is drawn from the API below, so there
is no markup anywhere that has to be kept in step with device state.

Requests are served from the render loop, which is also the floor on how fast
they can be: about 50 ms, almost none of it the handler. There are
measurements and the reasoning in
[docs/HTTP_LATENCY.md](HTTP_LATENCY.md), including one optimisation that
turned out not to work.

Each request costs a dropped frame or two. That is why the page polls at a leisurely rate and the responses are
kept small. The page schedules its next poll when the last one lands rather
than on a timer: the board serves one client at a time, so a timer would
leave requests outstanding behind each other until the browser ran out of
connections and the page stopped responding.

A request is only taken once all of it has arrived. Taking one blocks the
render loop until it has been read, and the web server would otherwise start
on the first byte and wait for the rest, up to five seconds a byte, with no
limit on the total. So the board looks at a waiting request once a frame and
leaves it there, eyes still moving, until it is whole. Several requests are
refused before any of it is read:

- a head over 3 KB gets `431`;
- a body over 2 KB, other than an eye file, gets `413`;
- an unreadable `Content-Length` gets `400`;
- a request that has not all arrived within five seconds is dropped.

See [Configuring](CONFIG.md) for the three limits.

WiFi modem sleep is turned off for the same reason. The default parks the
radio between beacons, which measured at a **1.7 s median** for one small
`GET`, with a tenth of them past eight seconds; with it off the same request
takes **65 ms** and none time out. It costs roughly 30 mA, which is nothing
for a prop on a USB lead.

## Serial console

Open `pio device monitor` and type `help`. Commands are line-based at 115200.

| Command | Effect |
| :--- | :----- |
| `eye` | List the eye designs, including one loaded from a file |
| `eye <name>` | Select a design by name, e.g. `eye dragon` |
| `eye <index>` | Select by number, e.g. `eye 1` |
| `eye next` | Cycle to the next design |
| `eye unload` | Empty the [eye slot](EYE_FILES.md); filling it takes the control page |
| `look <x> <y>` | Aim the gaze; each 0–1023, `512 512` is centre |
| `look auto` | Hand gaze back to autonomous motion |
| `dilate <0-100>` | Pupil width; `100` is fully dilated |
| `dilate auto` | Hand dilation back to autonomous |
| `startle` | Constrict slowly, then snap wide with a blink |
| `pupil [on\|off]` | Pupil, or a full iris disc |
| `clock [on\|off]` | Analogue clock in the iris |
| `clock set HH:MM[:SS]` | Set the time |
| `clock rate <1-3600>` | Run the clock faster, for testing |
| `clock secs [on\|off]` | Show or hide the second hand |
| `clock color [hour\|min\|sec] RRGGBB` | Hand colours |
| `blink` | Blink both eyes now |
| `swap [on\|off]` | Swap which physical panel is which eye |
| `dim [0-100]` | Brightness; 0 is off. Also `dim gamma <1.0-4.0>`, `dim trim left\|right <-50..50>`, `dim sweep [off]` — see [Brightness](BRIGHTNESS.md) |
| `flip left\|right [on\|off]` | Turn one panel's image through 180°, for a panel fitted upside down. Your left and right, facing the head |
| `cpu [160\|240]` | The CPU speed. Stored at once, and used from the next restart. 240 draws faster and draws more current — see [Frame rate](FRAME_RATE.md#brownouts-and-the-cpu-at-160-mhz) |
| `save` | Persist every setting tagged persistent — see [Configuring](CONFIG.md#remembering-settings) |
| `forget` | Clear saved settings |
| `restart` | Restart the board a second from now. Unsaved changes are lost, and it says so |
| `net [quiet]` | Address info, on the panels too — one eye shows a code that opens this page |
| `net off` | Dismiss the address cards early |
| `wifi` | The network, and how to change it |
| `wifi join <ssid> [pass]` | Store a network and reboot into it |
| `wifi forget` | Clear the stored network |
| `wifi portal` | Reboot into the setup portal |
| `version` | The board's name, firmware version, commit and build date |
| `ntp [on\|off\|sync]` | Use a time server, stop using one, or ask again now |
| `rtc` | Battery-backed clock: present, valid, its time and temperature |
| `rtc sync` | Store the current time in it |
| `tz [zone]` | Timezone by name or POSIX string |
| `splash` | Re-show the panel name cards |
| `status` | Current eye, gaze, dilation, CPU speed, heap, uptime, frame rate, and the longest core 0 has gone without its idle task — see [Frame rate](FRAME_RATE.md#drawing-and-sending-at-once) |
| `warnings` | What the board found at boot: damaged settings and what was done about them, a restart it did not plan, and a speed-up it had no memory for — see [Configuring](CONFIG.md#if-stored-settings-are-damaged) |
| `sleep` | What the sleep window is set to, and what it is doing |
| `sleep on\|off` | Enable or disable it |
| `sleep HH:MM HH:MM` | The window: when to sleep, then when to wake |
| `sleep level <0-100>` | `0` switches the panels off; above that, a share of the brightness setting |
| `help` | The list above. `?` does the same |

A reply starts with `ok` when something was done, `err:` when it was refused,
and `usage:` when the command was not understood; anything else is a report,
like `status` or `sleep` on its own.

The **BOOT button** cycles through the eye designs, which is handy on the
bench but unreachable once the head is assembled — hence the console. Held
for ten seconds it erases the settings instead; see
[Locking it down](SECURITY.md#forgetting-the-password).

Overrides are sticky: `look` and `dilate` hold their commanded value until you
return them with `auto`. The autonomous animation keeps running underneath, so
handing control back is seamless.

## REST API

Everything the page does, `curl` can do. **`/api/v1`**, JSON in and JSON out.
While no credential is required, CORS is open, so a page served from anywhere
can drive the device; with one, cross-origin pages are not invited.

| Method | Path | What it does |
| :----- | :--- | :--- |
| `GET` | `/api/v1/state` | Everything at once — what the page polls |
| `GET` | `/api/v1/eyes` | The eye designs, built in and loaded, and the state of the eye slot |
| `GET` `PUT` `DELETE` | `/api/v1/eyes/slot` | The [eye file](EYE_FILES.md) slot. `PUT` takes the file itself as the body |
| `GET` | `/api/v1/net` | MAC, addresses, signal, sync state |
| `GET` | `/api/v1/info` | Version, commit, build date, project URL, whether a credential is needed |
| `GET` `PUT` | `/api/v1/ntp` | Time-client status; `{"enabled":false}` stops it, `{"op":"sync"}` asks now |
| `GET` `PUT` | `/api/v1/rtc` | The battery-backed clock; `{"op":"sync"}` stores the time. Only with `RTC=1` |
| `GET` `PUT` | `/api/v1/eye` | `{"name":"dragon"}`, `{"index":2}` or `{"next":true}` |
| `GET` `PUT` | `/api/v1/gaze` | `{"x":200,"y":800}` or `{"mode":"auto"}` |
| `GET` `PUT` | `/api/v1/dilate` | `{"percent":40}` or `{"mode":"auto"}` |
| `GET` `PUT` | `/api/v1/pupil` | `{"on":false}` |
| `GET` `PUT` | `/api/v1/swap` | `{"on":true}` — swaps left and right panels |
| `GET` `PUT` | `/api/v1/dim` | `{"percent":40}`, `{"gamma":2.8}`, `{"trim":{"left":-15}}`, `{"sweep":true}` — any of them |
| `GET` `PUT` | `/api/v1/flip` | `{"left":true}`, `{"right":false}` or both — a panel fitted upside down |
| `GET` `PUT` | `/api/v1/cpu` | `{"mhz":240}` or `160`, stored at once and used from the next restart. Answers with `mhz`, the speed now, and `setting` |
| `GET` `PUT` | `/api/v1/clock` | `on`, `seconds`, `rate`, `time`, `colors` — any subset |
| `GET` `PUT` | `/api/v1/netinfo` | `{"on":true}` — address cards on the panels |
| `GET` `PUT` | `/api/v1/wifi` | `{"ssid":…,"pass":…}`, `{"op":"forget"}`, `{"op":"portal"}` |
| `GET` `PUT` | `/api/v1/tz` | `{"tz":"pacific"}` or any POSIX string |
| `POST` | `/api/v1/action` | `{"action":"blink"}` — also `startle`, `splash`, `netinfo`, `restart` |
| `POST` | `/api/v1/settings` | `{"op":"save"}` or `{"op":"forget"}` |
| `GET` `PUT` | `/api/v1/sleep` | `enabled`, `start`, `stop`, `level` — needs `SLEEP` |
| `GET` `PUT` | `/api/v1/credentials` | Which credentials are set, and changing them — see below |

```sh
# A body must be sent as JSON -- curl defaults to form encoding, which the
# ESP32 web server consumes before a handler ever sees it.
alias frank='curl -sH "Content-Type: application/json" http://frank.local/api/v1'

frank/state
frank/eye    -X PUT  -d '{"name":"dragon"}'
frank/gaze   -X PUT  -d '{"x":200,"y":800}'
frank/clock  -X PUT  -d '{"on":true,"colors":{"second":"FF8800"}}'
frank/action -X POST -d '{"action":"startle"}'
```

A `PUT` returns the resource as it now stands, so there is no need to `GET`
afterwards to find out what happened. Failures carry a reason:

```json
{"error": "x and y must each be 0-1023"}
```

`400` for a bad body, a field of the wrong type, or an out-of-range value —
checked before anything is applied, so a refused request changes nothing.
`404` for an eye design this board does not have, or an RTC or clock face the
build does not contain. `405` for the wrong verb on a real path. `409` when the
board's state is in the way: a time client that is off or has no link yet, an
RTC with no real time to store, an eye file whose name is taken, or a board with
no eye slot. `500` if storage fails. With authentication compiled in, `401` for a missing or wrong
credential and `403` for a `Host` that is not this device — or for changing a
credential without presenting the current one.

Every write to `/wifi` answers first and then reboots the board, so the reply
arrives but the connection it arrived over does not survive. `GET /wifi`
never returns a password.

`{"action":"restart"}` answers first too, and restarts the board a second
later, so a caller gets its `200` rather than a dropped connection it cannot
tell from a crash. Unsaved settings are lost; `system.settingsDirty` in
`/state` says whether there are any, and the control page asks before it
restarts. The board is back in about ten seconds with the same address.

Gaze runs `0`–`1023` on each axis with **`y=1023` at the top**, the way a
joystick reads rather than the way a screen does. `512 512` is centre. The
control page flips it so that dragging up looks up.

Authentication is off by default, and optional at build time: with the
switches off none of it is compiled in, and anything that can reach the board
can drive it. That is the right trade for a prop on a home network and the
wrong one anywhere else — see [Locking it down](SECURITY.md) for the three
mechanisms and how to turn them on.

## The `/cmd` escape hatch

For anything the API does not model yet, `/cmd?c=<command>` hands a line
straight to the console's dispatcher:

```sh
curl "http://frank.local/cmd?c=help"
curl "http://frank.local/cmd?c=status"
```

It returns plain text, not JSON, and it is a convenience rather than an
interface — prefer the API for anything you are writing against. Set
`WEB_CMD_ENDPOINT` to `0` to leave it out.

With digest authentication the command must be in the URL, as above. A
digest answer covers only the path and query it names, so a form-encoded
body is refused.

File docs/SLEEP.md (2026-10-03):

# Sleep mode

## Using it

A prop in a hallway does not need to stare all night. Between two times you
set, the panels go dark and the eyes stop being drawn.

```sh
sleep                      # what it is set to, and what it is doing
sleep on
sleep 22:00 07:00          # start, then stop
sleep level 0              # 0 switches the panels off; 1-100 is a share of the brightness
```

Or the **Sleep** card on the control page, or `PUT /api/v1/sleep`.

It goes dark using the panel's own command rather than by drawing black. An
OLED showing black pixels is already dark, so a frame of black would spend a
full SPI push to achieve what one byte does — and would leave the panel
driving its rows besides. Waking costs one command and no redraw, because the
panel's memory survives being switched off. Both are fades rather than jumps,
done by the [dimmer](BRIGHTNESS.md), and `sleep level` is a share of its
brightness setting.

**It will not sleep unless the board knows what time it is.** With no network,
no RTC and no hand-set time, it stays awake and says `waiting for the time`
rather than guessing. The clock face already hides itself under exactly this
condition; this follows the same rule for the same reason.

**A window that crosses midnight is the normal case**, and `22:00 07:00` means
what it looks like. Setting start and stop to the same time means *never*, not
always — a mistyped field should not leave a prop permanently dark.

**Anything you do wakes it for a minute.** A console command, the BOOT button,
or any API call that changes something. Reading does not count, deliberately:
the control page polls once a second while it is open, so counting reads would
mean a browser tab left open kept the head awake all night.

Changing the sleep settings themselves is the exception, from the console as
from the page: that is administration rather than someone in the room, so it
ends any hold instead of starting one. Otherwise setting a window that
includes now would leave the eyes up for another minute, and look like it did
nothing.

Sleep is the lowest-priority claim on the panels. An address card asked for at
3am still appears, an over-the-air update still shows its progress, and the
startup cards still run — each of those lights the panels for as long as it
needs them, and sleep takes them back afterwards.

One consequence worth knowing: a sleeping board reports `fps = 0`, because
nothing is being rendered — and so does one with the brightness at 0. In
`GET /api/v1/state`, `sleep.asleep` and `dim.shown` sit beside `system.fps`
so the zero can be told apart from a fault.

Design notes, including what was measured and what was only assumed,
follow below.

## How it was designed

This was written as a design before any of it existed, and is kept that way:
the constraints below are what shaped the result, and several of them are less
convenient than they first look. What was decided, and the one thing the
design did not anticipate, are recorded at the end.

## What "dark" means

Both panels can do this properly, in hardware, rather than by drawing black
pixels. Drawing black would be the obvious approach and the wrong one: it
costs a full SPI push per frame to display nothing, and an OLED showing black
pixels is already dark, so the expensive option buys nothing the cheap one
does not.

| | display off | dim |
| :-- | :-- | :-- |
| SSD1351 (colour) | `SSD1351_CMD_DISPLAYOFF` `0xAE` | `SSD1351_CMD_CONTRASTMASTER` `0xC7`, 0–15 |
| SSD1327 (grey) | `0xAE` | `0x81`, 0–255 |

Both are one command. `0xAF` brings the panel back, and the panel's contents
survive — GDDRAM is untouched by `0xAE`, so waking does not need a redraw,
only the command.

**Two facts worth having before choosing between them.** Neither is in this
document because neither has been measured:

- How much current a panel actually draws with the display off. These modules
  have their own boost converters, and a converter idling is not a converter
  off. `0xAE` may save much less than it sounds like it should.
- Whether "dim" is a useful state at all. At contrast 0 an OLED is very dark
  but not black, which in a dark room may read as a faint glow rather than as
  off. That could be charming or annoying and only looking at it will say.

Both are an evening with a multimeter. Worth doing before committing to a
`level` setting that turns out to have one useful value.

### One API change is needed

`SSD1327::cmd()` and `cmd1()` are **private** in `src/ssd1327.h`, so the
grey panel cannot be told anything from outside today. It needs two public
methods — `setPower(bool)` and `setContrast(uint8_t)` — rather than exposing
the raw command interface, which would invite writing arbitrary registers from
anywhere.

The colour side needs nothing: `main.cpp` already calls
`eye[e].display.writeCommand(...)` directly, in `drawEye()`.

## Where the time comes from

`timeLocalSecOfDay(uint32_t &out)` in `src/timekeeping.h` already returns local
seconds-since-midnight with the timezone and DST applied, and — the important
part — **returns false when the time is not known**.

That is the whole guard. A board that has never been told the time, has no
network and no RTC, must not decide it is 3am and go dark. The project already
has this instinct: the clock face hides itself under exactly the same
condition, and the README documents it. Sleep follows the same rule and for
the same reason.

So: if `timeLocalSecOfDay()` returns false, sleep never engages, and the
status says "waiting for the time" rather than "off" — because those are
different states and a user whose eyes failed to sleep deserves to know which
one they are in.

This makes sleep independent of `CLOCK` (the clock face) but dependent on
there being a time source at runtime: NTP, an RTC, or a hand-set time.

## The window

Two settings, `start` and `stop`, as local minutes-since-midnight. The
comparison has to handle the case that matters most, which is the one that
wraps:

```
asleep = (start <= stop) ? (now >= start && now < stop)   // 01:00 -> 06:00
                         : (now >= start || now < stop);  // 22:00 -> 07:00
```

The second line is the normal case for this feature and the first is nearly a
degenerate one, which is a good reason to write both and test both rather than
assume the obvious form.

`start == stop` needs a decision. **Recommendation: it means never sleep**,
not always. A zero-length window reading as "permanently dark" is a way for a
mis-typed field to make the prop look broken, and "never" is the safer
failure.

## Where it sits in the frame

`frame()` already has a precedence chain of things that can own the panels,
and sleep joins the bottom of it:

```
frame(), in src/main.cpp, in order:

  webPoll()                   <- everything above the returns keeps running
  fps accounting
  if (webRebootPending())     return;   an update is about to reboot
  if (netShowUntil)           return;   address cards
  if (splashPoll())           return;   startup cards
  if (sleepPoll())            return;   <- sleep went here
  frames++
  drawEye(...)
```

Below the address cards and the splash deliberately: someone who presses
"show address" at 3am wants the address, and an update landing overnight
should still say so on the panels. Sleep is the lowest-priority claim on the
displays, not the highest.

**`webPoll()` is at the top, well above every early return**, so a sleeping
board still serves the web UI and the API at full speed. That is not an
accident of this design; it is why the web server is polled where it is. Worth
stating because the first question anyone will ask is whether the thing
becomes unreachable at night.

### The consequence nobody will expect

`frames++` sits below the return, so a sleeping board reports **fps = 0**.

That is arguably correct — nothing is being rendered — but this project has
already shipped one bug where `system.fps` read zero and looked broken
(`239d0a0`). Reintroducing a zero, even a legitimate one, needs to be
deliberate and visible: the API should report `sleeping: true` alongside it,
and the page should say "asleep" where it would otherwise show a frame rate.
A number that is zero for a good reason still needs the reason attached.

## Waking

This is the real design question, and it is a matter of taste rather than
engineering. Three options:

1. **Sleep is sleep.** The window is the window; nothing wakes it early. The
   simplest to build and to explain, and the most likely to annoy someone who
   walks past at midnight and wants to show the thing off.
2. **Any command wakes it, until the window ends.** A gaze change, an eye
   change, anything through the API or console lights it up and it stays up
   until morning. Simple rule, easy to describe, but one stray poll from a
   script leaves the eyes on all night.
3. **A command wakes it for a while** — say sixty seconds, then back to sleep
   if the window is still open. Matches what a phone screen does, and matches
   `netShowUntil`, which this codebase already uses for exactly this shape of
   behaviour ("hold the panels until a deadline, then let go").

**Recommendation: 3**, with the duration as a setting and 0 meaning option 1.
It reuses a pattern that is already here, and the failure mode — eyes on for a
minute at 2am — is mild in both directions.

Option 2 is worth rejecting explicitly: the web page polls every second while
it is open, so "any request wakes it" would mean a forgotten browser tab keeps
the prop awake all night. Whatever the rule is, **the page's own polling must
not count as interaction.** Only state-changing requests should.

## Configuration

Following the project's existing patterns rather than inventing new ones.

**Compile-time**, in `config.h`, all `#ifndef`-guarded:

| | default | |
| :-- | :-- | :-- |
| `SLEEP` | `1` | The whole feature. `0` compiles it out entirely. |
| `SLEEP_START_MIN` | `22 * 60` | Built-in default, overridden by the stored value |
| `SLEEP_STOP_MIN` | `7 * 60` | |
| `SLEEP_WAKE_S` | `60` | How long interaction holds it awake; 0 for never |

**Stored**, in the existing `creeper` NVS namespace alongside the clock
settings, so `save`/`forget` and the factory reset already cover it: enabled,
start, stop, level.

**API**, `GET`/`PUT /api/v1/sleep`:

```json
{"enabled": true, "start": "22:00", "stop": "07:00",
 "level": 0, "asleep": false, "reason": "waiting for the time"}
```

`start`/`stop` as `"HH:MM"` strings rather than minute counts — the page needs
`<input type=time>` to produce exactly that, and a REST API that a human can
drive with `curl` is worth more here than two fewer string parses.

`asleep` and `reason` are read-only and are what the UI renders. `reason`
carries the case above: enabled, but no time source, so not sleeping.

**Page**: one card, tagged `persistent`, with an enable toggle, two time
inputs, and a line reading "asleep until 07:00" or "awake — sleeps at 22:00"
or "waiting for the time". Consistent with how the clock card already reads.

**Console**: `sleep` to show, `sleep on|off`, `sleep 22:00 07:00`, matching the
shape of the existing commands.

## Edge cases worth writing tests for

- **The window wraps midnight.** The main case, and the one a naive
  implementation gets wrong.
- **The time jumps.** An NTP sync landing at 02:00 can move the clock across a
  boundary in one step. Since the window is recomputed every frame from the
  current time, this resolves itself — but it means sleep must never latch a
  decision it made earlier.
- **A DST transition inside the window.** `timeLocalSecOfDay()` handles it;
  the test is that nothing else caches a local time across it.
- **Sleep engaging while the address cards are up.** The cards win until their
  deadline, then sleep takes over. Worth an explicit test because the
  precedence is easy to invert by accident.
- **Waking to draw.** If `0xAE` is used, *anything* that wants the panels —
  `showMessage()`, `netShow()`, the splash, an OTA progress card — has to turn
  them back on first. That argues for a single `displaySleep(bool)` helper
  that owns the command and a `displayWake()` that those callers go through,
  rather than scattering `0xAF` around. **This is the part most likely to
  produce a bug that only shows up at 3am**, which is the worst time to
  discover one.

## What this is not

Not a power-saving feature for the ESP32. The radio, the CPU and the web
server all keep running; only the panels go dark. Deep sleep on the ESP32
would mean the board stops answering, which is a different feature with a
different set of consequences, and is not this one.

Not a brightness schedule. One window, two times. A general-purpose "dim at
dusk, brighter at noon" curve is a larger thing, and if it is ever wanted it
should replace this rather than grow out of it.

## What was decided, and what it became

All three questions went the way the recommendations pointed.

1. **Both, with off as the default.** `SLEEP_LEVEL` is 0, which switches the
   panels off and stops rendering. Any value from 1 to 100 dims them instead
   (now to that share of the brightness setting — see below) and *keeps drawing*, so the eyes still move faintly — a nightlight rather
   than a sleep. Freezing the last frame at low contrast was the third option
   and would have looked like a fault rather than a setting.
2. **Awake for a minute after anything deliberate.** `SLEEP_WAKE_S` is 60, and
   0 makes the window absolute. The nudge is called from three places, each a
   real boundary rather than a sprinkling through the operations layer:
   `handleCommand()` (which `/cmd` also lands in), the BOOT button, and
   `guarded<>` in `api.cpp` for any method that is not GET or OPTIONS. That
   last condition is the important one — the page polls once a second, so
   counting reads would have meant a forgotten browser tab kept the head awake
   all night.
3. **`start == stop` means never.**

The one API change the design called for was made as proposed: `SSD1327` has
`setPower()` and `setContrast()`, and its raw command interface stays private.

### Then the dimmer

Sleep no longer switches the panels itself. Since the
[dimmer](BRIGHTNESS.md) arrived, `sleepPoll()` returns a fraction of the
brightness setting — 100 awake, the level asleep, 0 for off — and the dimmer
fades there, switches the panels off at 0, and tells the render loop when there
is nothing to draw. So a level of 50 with the brightness at 60% is 30%, and
going to sleep or waking is a fade rather than a jump. The commands in the
table above are still what reach the panels; the SSD1351's dim now uses its
colour channels as well as the master current, for finer steps.

### One thing the design did not have

`GET /api/v1/sleep` reports `now`, the board's own local time of day — the
very value the window is judged against.

It was added while writing the tests, which needed to know what time the board
thought it was in order to place a window around it. The obvious sources were
both wrong: `time` carries no local wall clock, and `clock.secondOfDay` can be
running at an accelerated `rate` for testing, which would have put every test
window in the wrong place and produced failures that looked like sleep bugs.

Reporting the number the decision is made from removes the guesswork for the
page too, which can now say what the board thinks the time is at the moment
that is the thing in doubt.

### The 3am bug, headed off

The design flagged this as the part most likely to break in the dark: with the
panels switched off, *anything* that wants to draw has to turn them back on
first, or an address card at 3am arrives invisibly.

It is handled in one place. `pushCanvas()` — which every card in the firmware
goes through, from the splash to the address cards to the OTA progress
display — calls `dimmerCard()` before it draws, which switches the panels on
and lights them at a readable level whatever sleep or the brightness setting
says. Both steps return at once when there is nothing to change, so callers
ask freely and nothing pays for asking. After the card's deadline the dimmer
fades back to wherever the eyes should be.

That is why sleep and the dimmer sit *below* the card checks in `frame()`
rather than above them: the cards return before either is reached, so they
never argue over the same frame.

### The card that said "asleep — sleeps in 2h 4m"

Seen on 2026-09-14, and it cannot be both. The API was fine; the page had
two sources. `/state`, polled once a second, carried whether the board was
asleep and why; the countdown came from `/sleep`, which the page fetches
once at load and after a change. The card merged the two, so a tab left
open across 22:00 showed a live "asleep" beside a countdown frozen at
whatever it was when the tab was opened. In the awake case the same
countdown simply never ticked, which nobody had noticed.

Fixed by giving `/state` the countdown as well — `changesInMinutes` and
`changesToAsleep`, the same fields `/sleep` reports — and having the card
render from that alone. Two halves of one sentence cannot disagree if they
came from the same reply; `/sleep` is now fetched for the settings fields
only. [`tools/test_api.py`](../tools/test_api.py) checks that the two
endpoints report the same countdown.

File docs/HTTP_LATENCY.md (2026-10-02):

# Why a 35-byte GET takes 50 ms

Notes for a change that was then built, measured over hours, and not kept —
the verdict is further down. The short version: every request costs about
a render frame, because that is how often the web server gets looked at, and
no amount of tuning inside that model removes it.

Measured on an ESP32 DevKit V1 with two SSD1327 panels, `gray_rtc` with
authentication on, rendering at 31–32 fps. Medians over 20 samples, taken with
`tools/test_api.py` and a curl timing breakdown.

## Where the time goes

| | bytes | tcp accept | handler | transfer | total | p90 |
| :--- | ---: | ---: | ---: | ---: | ---: | ---: |
| `OPTIONS` preflight | 38 | 14 | 47 | 0 | 73 | 89 |
| `PUT /eye` | 38 | 10 | 31 | 2 | 44 | 66 |
| `GET /eyes` | 99 | 9 | 28 | 2 | 44 | 61 |
| `GET /state` | 943 | 13 | 31 | 2 | 52 | 81 |
| `GET /tz` | 2558 | 12 | 43 | 7 | 64 | 86 |
| `GET /` (gzipped) | 9364 | 11 | 39 | 78 | 117 | 203 |

The important row is the first one. `OPTIONS` parses no body, touches no
device state and returns 38 bytes, and it is not meaningfully faster than
anything else. **The work is not the cost.**

`GET /state` builds the largest JSON document the API produces — forty-odd
fields across eight objects, including an I²C read when an RTC is fitted — and
it is 8 ms slower than a 99-byte reply. Serialisation is free at this scale.

## What the cost actually is

`webPoll()` is called from `frame()`, once per rendered frame. At 31 fps that
is every 32 ms. A request that arrives just after a poll waits most of a frame
before anything looks at the socket.

That is the whole story. Accept, read, parse, dispatch and respond all happen
inside a single `handleClient()` call — it falls through from `HC_NONE`
straight into `HC_WAIT_READ` in the same invocation — so there is exactly one
poll in the path, and its cost is the polling interval.

## What was tried and did not work

**Draining the state machine.** The hypothesis was that `handleClient()`
advances one step per call, so a request needed three polls — accept, then
read, then dispatch — and calling it in a bounded loop would collapse three
frames into one.

It gained nothing. Measured with and without, the floor stayed at ~50 ms.

Two things were wrong with it:

- The premise. `handleClient()` does not need a second call; see above.
- The first attempt made things actively worse. An idle `handleClient()` ends
  in `delay(1)` to yield, so looping six times cost six milliseconds of *every*
  frame whether or not anyone was connected. The frame rate fell from 32 to 28
  immediately.

The loop was removed. The lesson worth keeping: measure the shape of the
problem before optimising it, and measure again afterwards even when the
change "obviously" helps.

## What did work

- **Gzipping the page** (`tools/gen_page.py`). 25,360 bytes became 9,069 — the
  send went from roughly seventeen TCP segments to six, and `GET /` from 554 ms
  to about 100. It also saved 14 KB of flash. This was by far the largest win,
  because it was the only change that reduced the number of round trips rather
  than the time per round trip.
- **Trimming `/tz`.** It was sending the POSIX string for all 61 zones, which
  no client reads. 3,943 bytes became 2,558, and the p90 went from **3617 ms**
  to 86. That tail was retransmission timeouts on a reply that spanned several
  segments; making it fit in fewer removed them.
- **Polling a hidden tab fifteen times less often.** A page left open in a
  background tab was spending a kilobyte and a slice of the render loop every
  second, forever; it drops to once every fifteen.

The pattern: the wins came from sending less, not from working faster.

## The change considered: move the server off the render loop

The ESP32 has two cores. The Arduino `loop()` — and therefore the renderer and
the web server — runs on core 1. Core 0 runs the WiFi and lwIP stacks and is
otherwise largely idle.

Running the HTTP server in its own FreeRTOS task on core 0 would decouple
request latency from the frame rate entirely. The floor would become network
round-trip time, a couple of milliseconds on a LAN, instead of a frame.

```
  now                              proposed
  ┌──────── core 1 ────────┐       ┌──── core 1 ────┐  ┌──── core 0 ────┐
  │ loop()                 │       │ loop()         │  │ httpTask()     │
  │   frame()              │       │   frame()      │  │   handleClient │
  │     drawEye()          │       │     drawEye()  │  │     ↕ mutex    │
  │     webPoll()  ◄── 32ms│       │                │  │   state.h ops  │
  └────────────────────────┘       └────────────────┘  └────────────────┘
```

### What makes it harder than it looks

Every operation the API performs currently runs between frames, on the same
core as the renderer, which is why none of it needs a lock. That is the
property being given up.

Shared state that would need protecting:

- **The eye design pointers.** `applyDesign()` swaps five pointers that
  `drawEye()` dereferences as it scans. Changing them mid-render tears a frame.
  There is already a `swapPending` flag for the panel swap that exists for
  exactly this reason — the same discipline would have to cover eye selection,
  and the deferral would have to be driven from the render side.
- **The gaze and dilation targets.** Written by a handler, read every frame.
  Individually they are word-sized and benign; as a pair they can be read
  half-updated, which is a visible glitch rather than a crash.
- **The clock's colours and geometry.** Read per hand, per frame.
- **`Preferences`/NVS.** `save` performs a flash write. Doing that from
  another core while the renderer runs is fine, but two concurrent writers are
  not.
- **The panels themselves.** `netShow`, `showMessage` and the splash all push
  canvases over the same SPI bus the renderer uses. These must stay on the
  render side; a handler would have to request them, as `netinfo` and `splash`
  already do.

The honest assessment: the operations layer in `src/state.h` is the right seam
for this — it is already the single place device state is changed — but it was
written assuming a single thread, and making it thread-safe is a real piece of
work, not a decoration. A mutex around each operation plus a deferred-apply
flag for anything the renderer reads mid-frame is the shape of it.

### The alternative

`ESPAsyncWebServer` is event-driven and runs in the TCP task, which achieves
the same decoupling without a task of our own. It would mean rewriting every
route, and it brings its own reputation for lifetime and memory bugs. It
would also make the same thread-safety demands of `state.h`, so it does not
avoid the hard part — only the scheduling part.

### Is it worth it

Probably not yet. 50 ms is imperceptible for a button press, and the control
page polls once a second. The case for it would be a client that wants to
drive the eyes smoothly from outside — the aim pad is already coalescing
around this limit, and a 50 ms floor caps that at 20 updates a second.

If it is done, the order should be:

1. Make `state.h` operations individually safe to call from another task.
2. Add the deferred-apply discipline for anything the renderer reads.
3. Only then move the server, so a failure at step 3 is a scheduling bug and
   not a data race.

## The prototype: what happened when it was built

It is on the `http-task` branch, behind `HTTP_TASK`, **defaulting to off**.

### The safety work came first, and it holds

Following the order above: `state.h` operations take a recursive mutex, and
anything the renderer reads mid-frame is queued and applied between frames by
`statePollPending()`. The eye design was the case that mattered — five
pointers `drawEye()` dereferences per pixel — and it is queued now, alongside
the panel swap that always was. `netShow()` became a request too, because it
painted, and the SPI bus belongs to the render loop.

That part works. Six clients hammering the board for forty seconds, changing
the eye, the gaze, the clock colours and the pupil at once, over eleven
hundred requests across several runs:

- no reboots
- no read-back mismatches — every value read back matched what had just been
  set, which is what a torn write would break
- heap flat to within a kilobyte
- the render loop kept going throughout

The same stress against the unmodified build behaves the same way, including
the occasional timeout under six-way concurrency: that is the single-client
server saturating, not the task.

### Where to put the task was not obvious

80 identical `GET /api/v1/state`, one configuration per row:

| | median | p90 | p99 | max | over 500 ms |
| :--- | ---: | ---: | ---: | ---: | ---: |
| on the render loop | 64 | 78 | 129 | 134 | 0 of 80 |
| core 0, priority 1 | — | — | — | — | the 9 KB page took **2.5 s** |
| core 1, priority 2 | 59 | 120 | 2690 | **5675** | 4 of 80 |
| core 0, priority 10 | 52 | 73 | 109 | 715 | 1 of 80 |

Core 0 at priority 1 is the trap: core 0 is where the WiFi driver and lwIP
run, at priorities in the twenties, and a task at 1 underneath them never gets
the CPU it needs to drain a socket. That measurement is what made the choice
look like "core 1" rather than "a higher priority".

Core 1 at priority 2 improved the median and destroyed the tail. A median
that improves while a twentieth of requests take over half a second is not an
improvement.

Core 0 at priority 10 — above the idle task, below the stack it depends on —
beat the render loop on median, p90 and p99.

### The first comparison was wrong

The measurements above were taken over an afternoon, one configuration at a
time, minutes to hours apart. On that basis the task looked like a disaster:
requests that took 134 ms at worst on the render loop appeared to take three,
five, eleven seconds with the task on, and three consecutive runs of the test
suite took 17, 11 and 73 seconds.

Then the *unmodified* build started showing the same stalls — 1910 ms,
7637 ms, 2540 ms across three consecutive runs of a measurement that had
produced a maximum of 134 ms earlier the same day. The RSSI had drifted from
−48 dBm to −56.

The stalls were the radio, not the code. Comparing A measured at one time
against B measured at another had attributed them to whichever build happened
to be flashed when the air got worse.

### Measured properly, interleaved

Three runs of sixty identical `GET /api/v1/state`, alternating builds back to
back so that both see the same conditions:

| | median | p90 | p99 | max | over 500 ms |
| :--- | ---: | ---: | ---: | ---: | ---: |
| task off | 70 / 71 / 75 | 162 / 164 / 171 | 1807 / 2591 / 2513 | 1910 / 7637 / 2540 | 2, 3, 3 |
| **task on** | 55 / 54 / 62 | 71 / 75 / 81 | **88 / 94 / 118** | **103 / 143 / 147** | **0, 0, 0** |
| task off again | 60 / 64 / 58 | 80 / 178 / 93 | 104 / 355 / 101 | 106 / 1624 / 133 | 0, 1, 0 |

Aggregated: **the task build did not stall once in 180 samples; the render-loop
build stalled 9 times in 360.** The median is better too, by about ten
milliseconds.

There is a mechanism that fits. When the air is poor and a segment needs
retransmitting, the render-loop server can only touch the socket once per
frame — every 32 ms — so recovering from a loss is slow and compounds. A task
servicing it every millisecond handles the same loss promptly. The task helps
*most* exactly when conditions are worst, which is the opposite of what the
first, confounded comparison suggested.

### Verdict: measured over two hours, it is not worth it

`tools/soak.py` was written for this: it builds, flashes and measures both
configurations in every round, reversing the order each round, so both see the
same radio. Forty-five rounds, sixty samples per side per round, two hours.

(It now also records the signal strength on every row, which this run had to
establish by hand afterwards. The conditions a measurement was taken in belong
in the file with it.)

| | p90 | p99 | p99.9 | max | stalls over 500 ms |
| :--- | ---: | ---: | ---: | ---: | ---: |
| task | 105 | 280 | 1640 | 3890 | 14 of 2700 (0.52%) |
| render loop | 105 | 290 | 1360 | 3110 | 12 of 2700 (0.44%) |

The median difference is real and negligible. Paired by round, the task was
faster in 31 of 45 — a sign test gives p = 0.016, so the effect exists — and
it is worth **3.4 ms** on a request of about 58. Six per cent.

Everything else is a tie. p90 is the same number to the millisecond. p99
differs by three per cent. The stall rates, 14 events against 12, are noise.

And the stalls were never the firmware. They appeared in 12 of the 45 rounds
but on *both* sides in only 2, scattered across rounds and sides at random,
which is what an external cause looks like. Round 30: the task build's worst
request was 3890 ms and the render loop's was 287. Round 33: 232 ms and
1977 ms, the other way about. Whichever build happened to be flashed when a
burst of interference arrived wore the stall.

Conditions drifted through the run, as suspected: median 55 ms with 0.27%
stalls in the first half, 64 ms and 0.69% in the second.

So the task is not merged. Three and a half milliseconds does not buy a
threading model, a mutex, a deferred-apply queue, four configuration switches
and four times this project's comment density. It stays on the `http-task`
branch with this page as the reason.

### What was kept

The locking and the deferred applies, which are on `main`. They stand without
the task, because the hazard they close was already there: `applyDesign()`
swaps five pointers `drawEye()` dereferences per pixel, and the console could
already call it from `pollCommands()` at an arbitrary point in a frame.
Single-threaded, but not safe. `netShow()` splitting a request from the draw
finishes a discipline the code already half-had in `netShowUntil` and the
splash.

With one thread the rule those impose is one the renderer already followed:
changes land between frames. That costs a reader nothing.

### The lesson worth keeping

All three wrong turns on this page have the same shape. The drain loop was
optimising a mechanism that did not exist; this was measuring two things under
conditions that were not the same. In both cases the code looked plausible and
the first number agreed with the hypothesis.

Interleave the comparison. If A and B cannot be measured within seconds of
each other, the difference between them is not trustworthy -- and a sample of
180 is not a measurement of a 0.5% event. The second wrong turn was reading
"zero stalls in 180 samples" as evidence; at the rate the soak eventually
established, zero in 180 happens about two times in five by chance.

## The open questions, answered

Three questions stood at the end of the work above — where `webPoll()` sits
in the frame, what the remaining outliers were, and whether keep-alive was
worth it. A raw-socket
decomposition -- `tools/test_api.py --decompose N` -- and a plain ping
answered all three, and in the end they had the same answer.

### Where `webPoll()` sits in the frame

Settled by reading rather than measuring. `webPoll()` is near the top of
`frame()` and `drawEye()`, the SPI push, is the last statement in it. The
polls are one frame apart by construction, and there was never anything to
move.

Which leaves the number that prompted the question: a ~35 ms wait against a
32 ms frame, where even spacing should average half of one. That was an
artefact of charging the whole of a request to the board. `urllib` returns one
figure for the exchange; a raw socket can see the seam, because `connect()` is
the handshake by itself and the first byte back cannot arrive until the board
has been round the render loop. 200 requests for `/api/v1/info`, at 34 fps and
-61 dBm:

```
                        median      p90      p99      max
handshake                 25.6     53.6    290.0    558.5
wait + serve              37.8     73.0   2308.6   2442.1
rest of transfer           7.7     42.3   1898.5   2370.2
total                     79.6    150.5   2344.6   2996.6
```

A handshake is a round trip through lwIP's own task, before the sketch has any
say in it -- and its median is 25 ms. So roughly a third of a request is spent
before the render loop is even involved.

The shape of the wait says the rest. There is a hard floor at 15 ms -- not one
wait in 200 came in under it -- and then a flat spread out to about 50 ms.
That is a fixed network leg with one frame of polling on top of it, which is
exactly what the code predicts and nothing more. The poll contributes its half
frame, about 15 ms. It was never the 35.

### The remaining outliers

Confirmed: lost packets. The handshake phase is what proves it, because a slow
`connect()` finishes before the application owns the connection, so the
firmware cannot be the cause. Of 200 requests, six handshakes passed 100 ms:

```
2987, 1064, 242, 143, 111, 110 ms
```

The first three are the shape of exponential backoff -- about 250 ms, then 1 s,
then 1 s + 2 s -- which is what waiting out a retransmission timer looks like.

A ping settles it without any HTTP at all. 100 packets to the board: **6 lost**,
minimum 3 ms, average 27 ms, maximum 1056 ms. The link is quick when a packet
gets through, and the average is inflated entirely by the ones that don't.

The loss is not on the measuring side. This machine is on Ethernet, and loses
0 of 60 packets to the gateway at under 1 ms average. (Another device on the
same access point lost 37 of 60, but a sleeping phone looks like that too, so
take it as nothing more than a hint that the air is busy.)

That also retires the occasional `GET /rtc` at 663 ms. It was not
the I2C read.

### Keep-alive

Worth more than the ten milliseconds it looks like, for a reason easy to
miss. The
handshake is 25 ms of median, not 10 -- but the larger cost is that closing
every connection makes each request carry more packets, on a link that drops
6% of them.

A request with `Connection: close` is about seven packets: SYN, SYN-ACK, the
ACK carrying the request, the reply, and a teardown. At 6% loss, the chance
that a request gets through without waiting on a timer is 0.94^7, about 65%.
On an established connection it is three packets and 0.94^3, about 83%. So
keep-alive would not only save the handshake, it would roughly halve how often
a request hits a retransmission at all. That matches the tail we see: a fifth
of requests running well past a frame.

It is still not a cheap change. This `WebServer` hardcodes the header --
`sendHeader("Connection", "close")` in `_prepareHeader` -- and the code that
would hold a connection open is commented out in the library with a reference
to a Chrome bug. Reaching it means vendoring a core library into `lib/` and
maintaining a fork of it. For 25 ms on a prop, that is the wrong trade today;
it is written down here so the next person does not have to re-derive the
arithmetic before deciding.

### What actually governs responsiveness

In order, which the numbers now put beyond argument:

1. **The radio link.** 6% packet loss at -61 dBm, with a 3 ms floor and a
   1056 ms tail. Every outlier on this page traces back to it. Moving the
   head, or getting its antenna out of the foam, is worth more than any change
   to this firmware -- and costs nothing.
2. **Keep-alive**, for the handshake and the packet count both, at the price
   of forking a library.
3. **The polling interval**, worth about 15 ms on average and bounded below by
   the frame rate. It is the smallest of the three, and the only one that had
   been getting the attention.

Which is the fourth time on this page that the thing being optimised turned
out not to be the thing costing the time. The pattern is consistent enough now
to be the general lesson: measure the phase, not the total.

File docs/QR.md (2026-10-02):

# QR codes on the panels

Setting a head up means joining it to WiFi, and joining it to WiFi means
finding `frank-setup` in a list of networks and then finding the right page.
A QR code on the eye itself could replace both steps — a phone camera reads
it, joins the network, and the captive portal opens the page by itself.

The question was never whether an ESP32 can draw a QR code. It was whether a
phone can *read* one off a 128×128 panel sunk into an eye socket. This page is
the answer, measured rather than assumed.

## The short version

**It works, at version 3 or below.** The join code scans reliably from a range
of distances, with the panels mounted in their real positions in the head
rather than held conveniently on a bench. The feature is viable.

| | payload | version | modules | drawn | panel margin | result |
| :-- | :-- | :-- | :-- | :-- | :-- | :-- |
| WiFi join, ECC M | 41 bytes | 3 | 29×29 | 111 px | 8.5 px | **reliable** |
| WiFi join, ECC Q | 41 bytes | 4 | 33×33 | 123 px | 2.5 px | reads, but the phone struggles to latch |
| Address, ECC M | 23 bytes | 2 | 25×25 | 99 px | 14.5 px | **reliable** |

The join codes were measured with a 12-character password. The setup portal's
own password is 8 characters, which makes the code 37 bytes: still version 3
at ECC M and version 4 at ECC Q, so the rows stand.

Every one of them renders at **three pixels per module** — 128 divided by
anything in this range is three. So module size is not the variable. What
changes is how many modules there are and how much panel is left over.

## Why version 4 lost

More error correction sounds like the safer choice and is not. ECC Q buys
25% recovery against ECC M's 15%, but it pushes the code from version 3 to
version 4: thirteen percent more modules to resolve, across a code that fills
123 of the panel's 128 pixels with two and a half pixels to spare.

Error correction only helps *after* a decoder has locked onto the code. It
does nothing for the step that was failing, which is finding it at all. The
denser code was harder to see and no easier to read.

## The flicker, which was not what it looked like

Pointed at a camera, the panels beat visibly. The obvious suspect — the sketch
redrawing too fast — was wrong: each code is drawn once and then left alone
for fifteen seconds, so there was nothing of ours to slow down.

It was the panel scanning itself. `SSD1327::begin()` sent `0xB3 = 0x00`, the
slowest oscillator setting the controller has, and a slow panel scan beats
against a rolling shutter. Stepping `0xB3` through its range with one fixed
code on screen found `0xF0` — the fastest available — steady.

`begin()` sends `0xF0` now, so this is fixed for the eyes as well. The panels
had presumably always refreshed that slowly; nobody had noticed because nobody
had pointed a camera at them.

It took two goes. The commit that announced this fix added `setFrontClock()`
and `setPhaseLength()` — the accessors the sweep needs — and never touched the
value `begin()` sends. The sweep worked, `0xF0` was confirmed on hardware, this
page said it was fixed, and the eyes went on scanning at `0x00` for another
ten commits. What caught it was reading the diff before a merge and noticing
that the comment on `setFrontClock()` still described `begin()` as sending
`0x00` — which it did.

Worth the warning: a fix verified through a diagnostic path is verified for the
diagnostic path. The sweep proved the *value*, which was the hard part and the
part that felt like the work; it could not prove the value had been written
down anywhere that runs.

## Where the codes are

Both codes are on **Frank's left eye** — the one on your right as you face
him — because both are things you point a phone at, and his other eye is busy
saying the same thing in words for anyone who cannot.

Sides are given from Frank's point of view throughout, which is the convention
the rest of the documentation uses. The source says so too, though not
everywhere: the chip-select pin names came from upstream and are the viewer's,
and `src/main.cpp` flags the discrepancy where it defines them.

| when | Frank's left (your right) | Frank's right (your left) |
| :-- | :-- | :-- |
| the setup portal is open | code that joins `frank-setup` | network name, password, seconds left |
| `net`, or the button on the control page | code that opens `http://<address>/` | MAC, IPv4, signal |

Neither is a separate mode to find. The setup code appears whenever a head
has no network it recognises, which is the moment it is needed; the address
code appears on the address cards, which already existed.

Each says on the console what it drew:

```
> net
ok showing address cards for 12s -- `net off` to dismiss
[net] address code: http://192.168.123.166/
```

```
[net] no network; opening setup portal 'frank-setup'
*wm:StartAP with SSID:  frank-setup
[net] join code: WIFI:T:WPA;S:frank-setup;P:Y7DTFVY3;;
```

Those lines are worth their space. A panel that drew nothing and a panel that
drew the wrong thing look identical from across a room, and telling them apart
otherwise means pointing a phone at an eye and guessing. For the portal it
matters more: the board is not on a network while the portal is up — that is
what the portal is for — so serial is the only channel there is.

The portal line carries the password, which is deliberate. It is random per
session and already on a panel for anyone in the room to read; whoever is
watching the console has a cable in the board, which is nearer than that.

## Why the address code carries an address

`http://192.168.123.166/`, not `http://frank.local/`.

The name needs mDNS, which Windows resolves unreliably without Bonjour and
Android only reliably from 12 onward — the same trap
[Networking](NETWORK.md#over-the-air-updates) documents for over-the-air
updates. A QR that opens `frank.local`
would simply fail for a lot of people.

A dotted quad works anywhere on the subnet, and because the code is drawn live
it is always current, which a printed label could never be. It costs nothing:
23 bytes is still version 2, and fifteen characters is as long as an IPv4
address gets, so that is the worst case rather than a flattering one.

## Does the whole thing work

Yes, verified end to end on hardware:

1. The portal opens and Frank's left eye — your right — shows the join code.
2. A phone camera reads it off the eye and joins `frank-setup` — nobody
   types the network name or the password.
3. The captive portal opens the setup page by itself.
4. The network is chosen, the board connects, and comes back on it.

Which found a crash that had nothing to do with QR codes.

`wm.stopConfigPortal()` had been called unconditionally after the portal
loop since long before any of this. When the portal *succeeds*,
WiFiManager's own `process()` has already called `shutdownConfigPortal()`,
which resets the server and clears the active flag — so the second call
dereferenced a null server and panicked, `LoadProhibited`, inside
`shutdownConfigPortal()` itself.

It crashed on every successful setup and on no failed one. Every test that
ended in a sixty-second timeout passed, which is every test anyone had run:
until the join code made the portal quick enough to drive all the way
through, nobody had ever completed a setup. Making a feature usable is a way
of reaching the code nobody reaches.

Guarded with `getConfigPortalActive()`.

## What the test does not tell us

- **Anything about other phones.** One camera, one decoder, one pair of
  panels. Version 3 had margin at every distance tried, which is the reason
  to expect it travels, but that is an expectation and not a measurement.
- **Anything about lighting.** Everything here was read off a self-lit panel
  indoors. A head in direct sun, or behind the tinted lens a finished prop
  might have, is untested.
- **How well it survives the socket.** The panels were in their real
  positions, but a deeper socket narrows the angle a camera can read from,
  and nothing here says how much.

## A trap worth remembering

The first run of this test reported version 1, 21×21, for every payload —
including the 41-byte one, which version 1 cannot hold at any error correction
level.

`qrcode.c` carries `@TODO: Return error if data is too big` directly above its
init function, and means it: any length returns success. The fitting loop
tried version 1 first, trusted the return value, and stopped. The panels
displayed crisp, well-formed grids of nothing.

Had anyone scanned them, the failure would have read as *"phones cannot manage
this density"* — the exact opposite of the truth, and the conclusion that
would have killed the feature. The capacity table from ISO/IEC 18004 is now
checked before the library is asked to encode anything.

Each code is also dumped to serial as text. Scan that off a monitor: if it
reads there but not on the panel, the encoding is right and the problem is
optics.

## Running it

```sh
pio run -e qrtest -t upload -t monitor        # SSD1327 grey
pio run -e qrtest_rgb -t upload -t monitor    # SSD1351 colour
```

**USB only.** There is no network stack in this build, so flashing it over the
air leaves the board unreachable until somebody plugs a cable in.

The panel on your right — Frank's left, where the real codes go — shows the
code, and the one on your left says which code it is, so a photograph of the
pair documents itself.

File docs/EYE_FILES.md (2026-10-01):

# Eye files

One eye design beyond the built-in ones, loaded from a file through the control
page and kept on the board until it is replaced or removed. The firmware ships
with `default` only. Any of the other designs in the [gallery](EYES.md#gallery)
can go in the slot without rebuilding anything.

## Using it

1. Build an eye file (`dragon.bin`, say) with
   [`tools/make_eye.py`](../tools/make_eye.py), as below.
2. On the control page, in the **Eye** card, choose the file under
   **load an eye file** and press **load**.
3. The panels read `EYE LOADING` for five to eight seconds, then the new design comes
   up and joins the eye list after the built-in ones.

Loading another file replaces the design already in the slot. **remove**
empties the slot. If the eyes were showing the removed design, they go back to
`default`. `save` remembers the design by name, as it does for any other, so a
head that was showing `dragon` when saved comes back up showing `dragon`.

The console can see the slot but cannot fill it, since a serial line is no way
to deliver 158 KB:

```
> eye
  0  default
  1  dragon      <- current   (loaded from a file)
> eye unload
ok slot empty; eye=0 default
```

### Building eye files

```sh
uv run tools/make_eye.py dragon        # one design -> dist/eyes/dragon.bin
uv run tools/make_eye.py --all         # every header in include/ -> dist/eyes/
```

`--all` includes `default.bin`, which the board refuses because a design by
that name is built in. It is there for a build that leaves `default` out.

It reads the same headers the firmware compiles in (`include/eyes/*.h`,
`include/defaultEye.h`, `include/newtEye.h`) and writes the tables out as raw
little-endian bytes behind a header. You don't need Pillow or a TeensyEyes
checkout for this. Those are only needed for
[regenerating the headers](EYES.md#adding-or-regenerating-designs).

## The one-time USB flash

The design lives in its own flash partition, `eyes`. A board's partition table
is written only by a USB flash. An over-the-air update replaces the firmware
but keeps the old table, so a head updated over the air runs the new firmware
without a slot:

- the control page says **this board has no eye slot** instead of offering an
  upload,
- `GET /api/v1/eyes/slot` reports `"available": false`,
- and everything else works as before.

Flash it once over USB (`pio run -e gray_rtc -t upload`) and the slot appears.
Settings, credentials and WiFi survive, because `nvs` has not moved. After
that, over-the-air updates work as they always have.

### Where the room came from

[`partitions.csv`](../partitions.csv) replaces the stock `min_spiffs.csv`. The
two app slots each give up 64 KB, and the unused SPIFFS partition goes:

| partition | offset | size | was |
| :-- | :-- | :-- | :-- |
| `nvs` | `0x9000` | 20 KB | unchanged |
| `otadata` | `0xE000` | 8 KB | unchanged |
| `app0` | `0x10000` | 1856 KB | 1920 KB |
| `app1` | `0x1E0000` | 1856 KB | 1920 KB |
| `eyes` | `0x3B0000` | 256 KB | *(SPIFFS, 128 KB, unused)* |
| `coredump` | `0x3F0000` | 64 KB | unchanged |

`coredump` stays because the Arduino core writes crash dumps to it. An eye file
is 158,400 bytes, so the slot has room for the format to grow.

Dropping `newt` from the default build frees about 158 KB of app space, which
more than covers the 64 KB each slot gave up.

## The file format

Little-endian throughout, like the ESP32 itself.

| offset | size | field |
| :-- | :-- | :-- |
| 0 | 8 | magic: the ASCII bytes `CREEPEYE` |
| 8 | 2 | format version: `1` |
| 10 | 2 | header size: `64` |
| 12 | 4 | payload size: `158336` |
| 16 | 16 | name, NUL-padded |
| 32 | 32 | SHA-256 of the payload |
| 64 | 158,336 | payload |

The payload is the five tables the renderer reads, one after another, each in
the same row-major layout as its C array:

| table | type | dimensions | bytes |
| :-- | :-- | :-- | --: |
| sclera | `uint16_t` RGB565 | 200 × 200 | 80,000 |
| iris | `uint16_t` RGB565 | 64 × 256 | 32,768 |
| upper eyelid | `uint8_t` | 128 × 128 | 16,384 |
| lower eyelid | `uint8_t` | 128 × 128 | 16,384 |
| polar | `uint16_t` | 80 × 80 | 12,800 |

Version 1 means exactly these dimensions. They're the ones the renderer is
compiled for, and the firmware checks at compile time that the two agree. A
file that differs in anything is rejected. The firmware never tries to adapt
one.

**The name** must be 1–15 characters of `a-z` and `0-9`, starting with a letter,
and must not be the name of a built-in design, nor `list`, `next`, `toggle` or
`unload`, which the console's `eye` command would read as its own words. Uniqueness is what lets `save`
store a design by name. The character set is what lets the name go straight
into JSON, the console and the page without escaping.

One file serves every build. Colour and greyscale panels render from the same
RGB565 tables, and the greyscale conversion happens as each frame is packed
for the panel.

## How it works

**No copy in RAM.** The board has no PSRAM, and 158 KB is about half the RAM it
has. The partition is mapped into the address space with `esp_partition_mmap()`,
and the renderer's five artwork pointers point straight into it. That's how the
compiled-in designs are read too: `const` arrays live in flash and are reached
through the same cache. `drawEye()` does not know which kind it is drawing.

**Streamed to flash.** `PUT /api/v1/eyes/slot` carries the file as the raw
request body. The web server hands it over in pieces of about 1.4 KB, and each
piece is written and hashed as it arrives, so the whole file is never in RAM.

**The header is written last.** The upload's first 64 bytes are held in RAM and
checked before anything is erased: magic, version, sizes and name, plus the
request's `Content-Length`. A file that is plainly wrong is refused with the
slot untouched. Once the header passes, the slot is erased, the payload is
written behind the header's space, and the hash is compared. Only if the hash
matches is the header itself written. A cut connection, a power cut, or a hash
mismatch at any point before that leaves a slot with no valid header, which the
board treats as empty. There is no half-loaded design that could be drawn.

**Checked again at boot.** Startup maps the slot, checks the header, and hashes
the payload before listing the design. This takes a few milliseconds, with the
ESP32's SHA hardware.

**Moving off before erasing.** If the eyes are showing the loaded design when a
new upload is accepted, or when `eye unload` runs, they switch to `default`
*before* the partition is erased or unmapped. Otherwise the renderer would be
holding pointers into memory that is about to change. That switch is immediate
rather than queued for the next frame, as other design changes are. It can be
immediate because web requests and console commands are both handled inside
the render loop, between frames, so nothing is mid-draw.

**The eyes stop while it loads.** Requests are served from the render loop, so
the upload is time without animation: about a second and a half over WiFi on
frank-dev, writing the file included, measured with a digest login that sends
it twice. A file the board refuses still has to be received before the refusal
can be sent, about 0.6 s. The panels say `EYE LOADING` so a frozen eye doesn't
look like a crash.

It used to be 5–8 seconds, and most of that was waiting, not receiving. The
web server reads a body 1436 bytes at a time and waits for each byte up to
its read timeout, five seconds. The file is 158400 bytes, which leaves 440 for
the last read. That read asked for a full 1436, got the 440, and waited out
the timeout for the rest — every upload, refused or not.

### Security

An upload is a write to flash, so it gets the same credential check as every
other change, and one step more. The web server delivers a raw body *before*
the route's handler runs, and the handler is where the usual check lives. So
the upload path runs the same check itself, silently, before accepting a
single byte. An unauthenticated upload is read and thrown away, then refused
with the usual `401` or `403` by the handler. Nothing is erased. This also
covers a browser sending the body once without credentials and then again
with them.

An upload is also cut off after 30 seconds, and a refused one after 10. The
board waits for each piece of the body itself, against that deadline, and
only then lets the web server read it, so the server's reads never wait at
all. Left to the server, a sender trickling one byte at a time could hold the
render loop, and the eyes, for as long as it liked: the server's wait starts
again with every byte. The cut-off that was meant to stop that never did. It
closed a copy of the connection, which leaves the real one open. A real
upload takes about a second.

Nothing in the file is executed. Only the 64-byte header is parsed, and every
field in it is checked against a fixed value or a fixed range. The payload is
pixels and lookup tables, read by a renderer that indexes each table only with
values bounded by its dimensions. The hash protects against corruption, not
against a malicious file. There is nothing to sign, because the worst a
well-formed file can do is look ugly.

## API

| method | path | |
| :-- | :-- | :-- |
| `GET` | `/api/v1/eyes/slot` | `{"available":true,"loaded":true,"name":"dragon","index":1,"capacity":262144}` |
| `PUT` | `/api/v1/eyes/slot` | the file as the body, `Content-Type: application/octet-stream`. Replies as `GET`, having selected the new design |
| `DELETE` | `/api/v1/eyes/slot` | empties the slot. Replies as `GET` |

Errors are JSON `{"error": "..."}` like everywhere else. A file that is not a
valid eye file gets `400`. A name that clashes with a built-in design or a
console word, or a board with no slot, gets `409`. A flash failure gets `500`.

```sh
curl -T dist/eyes/dragon.bin -H 'Content-Type: application/octet-stream' \
     http://frank.local/api/v1/eyes/slot
```

`GET /api/v1/eyes` lists the loaded design after the built-in ones, with
`"loaded": true`.

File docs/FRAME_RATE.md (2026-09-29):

# Frame rate

How the colour eyes went from 19 frames a second to 51, measured one change
at a time on frank-dev: a DevKit on the rev A carrier board, two SSD1351 colour
panels, WiFi up, the default eye. The greyscale ones, on Frank, went from 33 to
75; see [Greyscale](#greyscale).

## Reading the numbers

The serial heartbeat prints, once a second:

```
[creeper-eyes] fps=53 draw=4.2ms wait=13.1ms send=18.4ms other=1.0ms heap=...
```

- **fps** counts eyes drawn, and the two eyes take turns, so each eye is
  updated half that often. At 53, each eye gets about 26 new frames a second.
- **draw** is computing one eye's pixels.
- **send** is putting them on the panel's SPI bus.
- **wait** is the render loop waiting for the previous frame to finish
  sending. It is only non-zero with `OVERLAP_SEND`, below.
- **other** is everything else the render loop does: the web server, OTA, the
  motion code.

A frame is `draw + wait + other`. Without the overlap it is `draw + send +
other`.

## What each change did

| change | fps | draw | send | other |
| :-- | --: | --: | --: | --: |
| As it was: bus at 8 MHz, flash at 40 MHz DIO | 19 | — | ~33 ms | — |
| Colour bus to 16 MHz (`SSD1351_SPI_HZ`) | 29 | 13.2 ms | 18.5 ms | 2.2 ms |
| Compiled with `-O2` instead of `-Os` | 28.5 | 13.7 ms | 18.5 ms | 2.2 ms |
| Flash at 80 MHz DIO | 35 | 8.6 ms | 18.4 ms | 1.2 ms |
| Flash at 80 MHz QIO | 38 | 6.2 ms | 18.3 ms | 1.1 ms |
| Polar map and iris in RAM (`RAM_TABLES`) | 41 | 4.5 ms | 18.3 ms | 1.0 ms |
| Sending on the other core (`OVERLAP_SEND`) | 53 | 4.2 ms | 18.4 ms | 1.0 ms |
| CPU at 160 MHz instead of 240 | 51 | 5.8 ms | 19.4 ms | 1.1 ms |

Medians over about twelve one-second heartbeats each. The first row predates
the timing, so only the send is known: 32 KB at 8 MHz.

### The bus

A colour frame is 128 × 128 × 2 bytes, 32 KB, four times a greyscale one, and
the colour panels ran at the Adafruit library's default of 8 MHz. The SSD1351 is
rated to 20 MHz. That gave 30–31 fps, but speckled one of the two panels on the
carrier board. 16 MHz, the next speed the ESP32's 80 MHz divides to exactly, is
clean. It is `SSD1351_SPI_HZ`.
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

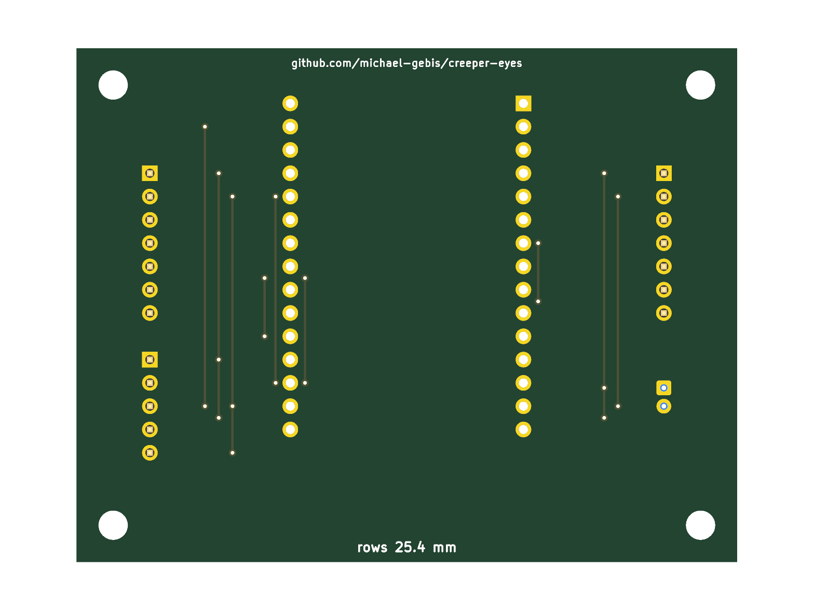
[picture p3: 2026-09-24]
hardware/rows-25.4mm/images/board-bottom.png

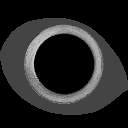
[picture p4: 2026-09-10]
docs/images/eyes/leopard_normal_grey.png

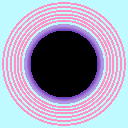
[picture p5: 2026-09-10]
docs/images/eyes/toonstripe_dilated.png

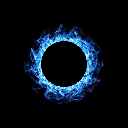
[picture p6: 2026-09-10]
docs/images/eyes/blueFlame1_constricted.png

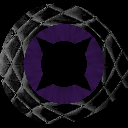
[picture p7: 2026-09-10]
docs/images/eyes/spikes_constricted.png

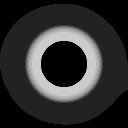
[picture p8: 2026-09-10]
docs/images/eyes/fizzgig_constricted_grey.png

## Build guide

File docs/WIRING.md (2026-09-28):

# Wiring the eyes

Two 1.5" 128×128 OLED panels onto an ESP32 DevKit V1. Seven signals per
panel, fourteen
wires, one shared SPI bus.

This is the same for **both** panel types — the Waveshare 1.5inch RGB OLED
(SSD1351) and the 1.5inch OLED (SSD1327) have identical 7-pin headers. Only
the build differs: `esp32dev` for colour, `gray` for grayscale.

## Connections

Six of the seven are shared by both panels. Only chip select differs —
that is the whole trick to driving two panels off one bus.

Left and right are **Frank's own**, the way anatomy is always described: facing
him, his right eye is the one on your left.

| Signal | DevKit pin | Frank's right (your left) | Frank's left (your right) | Purpose |
| :----- | :--- | :--- | :--- | :--- |
| VCC | `3V3` | VCC | VCC | Power. **Not VIN.** |
| GND | `GND` | GND | GND | Common ground, both panels |
| DIN | `D18` | DIN | DIN | SPI data — pixels travel here |
| CLK | `D5` | CLK | CLK | SPI clock |
| DC | `D33` | DC | DC | Data / command select |
| RST | `D27` | RST | RST | Shared reset, pulsed once at boot |
| CS | `D15` | CS | — | Selects Frank's right panel only |
| CS | `D4` | — | CS | Selects Frank's left panel only |

There is **no MISO connection**. The panels never talk back, so GPIO19 takes
no wire. It is not free for anything else, though: `SPI.begin()` hands it to
the SPI peripheral as MISO regardless — see the pin table below.

Suggested jumper colours, so the harness stays readable once it is buried in a
head: red VCC, black GND, yellow DIN, blue CLK, green DC, violet RST, and two
distinct colours for the chip selects.

## Bus topology

```
                     ┌──────────────┐
                     │  Frank's     │
              ┌─────►│  RIGHT eye   │
              │   ┌─►│  (your left) │
              │   │  └──────────────┘
  ┌────────┐  │   │
  │        │  │   │   VCC GND DIN CLK DC RST   shared by both
  │ ESP32  ├──┴───┼── ────────────────────────────────────┐
  │        │      │                                       │
  │  D15   ├──────┘   CS, Frank's right only              │
  │  D4    ├──────┐   CS, Frank's left only               │
  └────────┘      │  ┌──────────────┐                     │
                  └─►│  Frank's     │◄────────────────────┘
                     │  LEFT eye    │
                     │ (your right) │
                     └──────────────┘
```

Six signals fan out to both panels, two chip selects go one each: 6×2 + 2 = 14
physical connections.

## Before you connect anything

### 3V3, never VIN

The ESP32's GPIOs are 3.3 V and **not 5 V tolerant**. `VIN` carries 5 V
straight from USB.

The Waveshare modules are 3.3 V / 5 V tolerant and will survive either, but
their logic pins would then be driving 5 V back into the ESP32. Use `3V3`. It
is the correct rail for both panel types, and no level shifting is needed.

> Waveshare's own documentation warns: *"Please ensure that the power supply
> voltage and logic voltage are consistent, otherwise it will not work
> properly."* Powering from 3V3 keeps both at 3.3 V.

### Silkscreen labels vary

Modules from different sellers name the same pins differently:

| This guide | Also seen as |
| :--- | :--- |
| **DIN** | SDA, SI, MOSI, DATA |
| **CLK** | SCL, SCK, D0 |
| **RST** | RES, RESET |
| **DC** | D/C, A0, RS |
| **CS** | OCS, SS |

A module labelled SDA/SCL is still **SPI** here, not I²C. Match by position in
the table, not by the letters.

### Interface mode

Both Waveshare modules ship configured for **4-wire SPI**, which is what this
project uses. That is set by solder jumpers on the back — `BS0` on the RGB
module, `BS1`/`BS2` on the grayscale one. If you have not touched them, they
are already correct.

### Power budget

Two 128×128 OLEDs draw roughly 20–40 mA each at typical content, more on bright
frames and at the top of the [brightness](BRIGHTNESS.md) range. The ESP32 draws
more than either: its WiFi is on and kept awake, for responsiveness, and
transmit bursts spike hard. None of these figures has been measured on this
project. It fits a 500 mA USB port, but that port and its cable should be
decent ones; a brownout, below, is what a weak one looks like.

### Use the breadboard rails

Run one wire from `3V3` to the red rail and one from `GND` to the blue, then
tap both panels off the rails. Fourteen connections become ten jumpers from the
board, and the power runs stay short.

## Order of assembly

Power off and USB unplugged throughout.

1. **Ground first.** `GND` to the blue rail, then a lead to each panel. A panel
   powered without a common ground can find its return path through a data pin.
2. **Then 3V3.** To the red rail, then to each panel. Confirm you are on `3V3`
   and not the adjacent `GND` or `VIN` — on the 30-pin board `3V3` is the very
   last pin on the right-hand header.
3. **Shared signals.** `D18`→DIN, `D5`→CLK, `D33`→DC, `D27`→RST, each landing
   on both panels.
4. **Chip selects last.** `D15` to Frank's right panel, `D4` to his left. These
   are the only two wires that differ, so they are the two worth
   double-checking.
5. **Re-check 3V3 and GND** at both modules before plugging in USB. Reversed
   power is the one mistake that ends the evening.

## First power-on

Flash the build that matches your panels — `esp32dev` for SSD1351 colour,
`gray` for SSD1327 grayscale — then power up.

### What correct looks like

1. Each panel names itself for five seconds: `FRANK'S RIGHT` over `YOUR LEFT`,
   or the reverse.
2. Both panels animate: irises drifting and rescaling, occasional blinks.
3. The blue on-board LED toggles once a second.

**If the labels are swapped** relative to the face, the panels are on the
opposite chip selects from what the code assumes. That is a two-line fix in
the `swap` setting, far easier than rewiring: `swap on` then `save`, or
the **swap panels** button on the control page. That is a real swap, not
a relabelling — the eyelid mirroring moves with it.

**If a label is upside down**, that panel went in rotated. `flip left` or
`flip right` — your left and right, as the label says — turns its image
round, and `save` keeps it. See [Eyes](EYES.md#if-a-panel-is-upside-down).

### The frame rate will not change

The serial heartbeat reports roughly `fps=50` on colour panels, and more on
grayscale — counted per eye drawn, and the two eyes take turns, so each eye
is updated half that often. Beside it, `draw`, `wait`, `send` and `other` split
each frame's time up; [Frame rate](FRAME_RATE.md) explains them. The figures depend on what else the build is
doing, since the web server is polled from the same loop, which is why those in
[HTTP_LATENCY.md](HTTP_LATENCY.md) are lower. And it reports the same with
**nothing connected at all**. The SPI peripheral clocks the same bytes out
whether a panel is listening or not.

So an unchanged frame rate tells you *nothing* about whether the panels are
wired correctly. Trust your eyes, not the number.

It counts frames actually drawn, so it reads **zero** while something else
owns the panels — the boot splash, or the twelve seconds of address cards
after `net` — and while the brightness is at 0 or the head is asleep with its
panels off. That is correct rather than alarming: during those, no eye is
being rendered.

### Watch the console

```sh
pio device monitor
```

A `rst:0xc` or a brownout message the instant you connect the second panel
points at power, not at data wiring.

## If something is off

| Symptom | Most likely cause |
| :--- | :--- |
| **Both panels show white static** | Wrong controller for the build. SSD1351 init means nothing to an SSD1327, and vice versa — the panel shows uninitialised memory. Colour panels show *coloured* speckle; monochrome ones show white. Run `pio run -e probe1327 -t upload -t monitor`: if the panels respond, they are SSD1327 and you want the `gray` build. |
| Both panels dark | Power, or `D27` held low. Check 3V3 and GND at the module pins, not at the rail. A panel held in reset stays black. |
| One panel dark, one fine | That panel's `CS`, or its own power. Everything else is shared, so a shared-signal fault would take out both. |
| Noise or garbage, not static | `DC` on `D33`, or clock integrity. Commands are being read as pixels, or the reverse. |
| Flicker, tearing, speckle | Breadboard signal integrity. Shorten the `CLK` and `DIN` jumpers, keep them away from the power runs, and lower the bus speed: `SSD1351_SPI_HZ` on colour, which runs at 16 MHz, or `SSD1327_SPI_HZ` on grayscale. |
| Both panels show the same content | A `CS` line shorted or on the wrong row — both panels selected at once. |
| Board resets when a panel connects, or now and then under load | Brownout — the control page says so after it restarts, and a board set to 240 MHz drops back to 160 by itself. Move to a powered hub or feed 5 V to `VIN`, and on the [carrier board](../hardware/README.md) fit C1. See [Frame rate](FRAME_RATE.md#brownouts-and-the-cpu-at-160-mhz). |
| Board will not boot at all | Check nothing has crept onto `D12`. Held high at reset it stops the board starting. None of the eye signals use it. |

Isolating a fault is easiest one panel at a time: unplug one entirely and
confirm the other works alone, then swap. The chip selects are independent, so
either panel runs fine on its own.

For a lower-level check, `displaytest` drives each panel with nothing but solid
colour fills at 2 MHz:

```sh
pio run -e displaytest -t upload -t monitor
```

If solid colours appear there, the wiring, the bus and the init sequence are
all good, and any remaining fault is in the eye rendering.

## Pin reference

Every pin this project uses is broken out on the 30-pin DevKit V1:

| GPIO | Silkscreen | Role here | Notes |
| :--- | :--- | :--- | :---- |
| 4 | `D4` | CS, Frank's left | |
| 5 | `D5` | CLK | Strapping pin; must be high at boot, which SPI idle satisfies |
| 15 | `D15` | CS, Frank's right | Strapping pin; CS idles high, so this is fine |
| 18 | `D18` | DIN | |
| 19 | `D19` | *(taken by SPI)* | Nothing is read back, but `SPI.begin()` attaches the peripheral to it |
| 21 | `D21` | *(free)* | I²C data, if the optional RTC is fitted |
| 22 | `D22` | *(free)* | I²C clock, if the optional RTC is fitted |
| 27 | `D27` | RST | |
| 33 | `D33` | DC | |
| 2 | *(no header pin)* | Heartbeat LED | On-board blue LED |
| 0 | *(no header pin)* | Cycles eye designs; held 10 s, factory reset | BOOT button |

`GPIO12` is deliberately unused: held high at reset it selects a 1.8 V flash
voltage and the board will not start. Keep it clear.

## Optional add-ons

None of these are needed for the eyes to work, and each is compiled out by
default:

- **[A battery-backed clock](WIRING_RTC.md)** — a DS3231 on four wires, so the
  head knows what time it is after a power cut or with no network at all.
- **[A circuit board](../hardware/README.md)** in place of the breadboard and
  its fourteen jumpers.

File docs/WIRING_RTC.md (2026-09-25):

# Wiring the battery-backed clock — optional

**You do not need this.** The eyes, the clock face, and everything else work
without it. Skip this page unless you want the head to know what time it is
after a power cut, or without a network at all.

Four wires, one small board, and a coin cell.

## What it buys you

| | Without an RTC | With one |
| :--- | :--- | :--- |
| No network, ever | No clock face at all until you set the time, and again after every power cut | Set it **once**; kept for the life of the cell |
| Network, then a power cut | Right again a few seconds after NTP answers | Right immediately at boot |
| Network goes away for good | Free-runs and drifts | Keeps time to about a minute a year |

The DS3231 is temperature-compensated — ±2 ppm, so roughly **a minute a
year**. That is far better than the ESP32's own crystal, which is what the
free-running fallback rides on.

## What to buy

Any **DS3231** module. These are sold as "DS3231 AT24C32 IIC precision RTC
module" or by the board name **ZS-042**, usually in multipacks of three or
four for a few pounds. The one this was written against is
[a four-pack of the 3.3V/5V board](https://www.amazon.com/dp/B08X4H3NBR).

The smaller five-pin **"DS3231 mini"** sold for the Raspberry Pi works as well.
Its pins are labelled `+ D C NC -`: VCC, SDA, SCL, nothing, GND. Rev B of the
[carrier board](../hardware/README.md) takes it directly.

The ZS-042 boards carry an AT24C32 EEPROM alongside the clock chip. This project does not
use it; it sits harmlessly at a different address.

Two things the listings do not tell you:

- **The coin cell is usually not included** — lithium cells are awkward to
  ship. You want a **CR2032**, or a rechargeable **LIR2032**; see the warning
  below before you choose.
- **Do not buy a DS1307.** It looks identical and is a fraction of the price,
  but it is 5V-only and has no temperature compensation, so it drifts by
  minutes a month.

## Connections

Four wires. The board is `3V3`-tolerant, which is what we want anyway — see
the battery warning.

| Signal | DevKit pin | RTC module | Purpose |
| :----- | :--- | :--- | :--- |
| VCC | `3V3` | VCC | Power. **Not VIN** — see below |
| GND | `GND` | GND | Common ground |
| SDA | `D21` | SDA | I²C data |
| SCL | `D22` | SCL | I²C clock |
| — | — | `32K` | Leave empty |
| — | — | `SQW` | Leave empty |

GPIO21 and GPIO22 are the ESP32's default I²C pins and are **not used by the
displays**, so this adds nothing to the existing harness — it hangs off two
otherwise idle pins and the power rails you already ran.

```
  ┌────────────┐
  │   ESP32    │        ┌───────────────────┐
  │            │        │  DS3231 / ZS-042  │
  │  3V3   ────┼────────┤ VCC               │
  │  GND   ────┼────────┤ GND               │
  │  D21   ────┼────────┤ SDA        (coin  │
  │  D22   ────┼────────┤ SCL         cell) │
  │            │        │ 32K  ── unused    │
  │            │        │ SQW  ── unused    │
  └────────────┘        └───────────────────┘

  The displays keep D18, D5, D33, D27, D15 and D4 exactly as they were.
```

Suggested jumper colours, to stay consistent with
[the eye harness](WIRING.md): red VCC, black GND, and two colours you have not
already used for SDA and SCL.

## Read this before you fit a battery

The ZS-042 board has a trickle-charging circuit — a 200 Ω resistor and a
1N4148 diode — designed for a **rechargeable LIR2032**. Boards are very often
sold or fitted with a **non-rechargeable CR2032** instead, and continuously
trickle-charging one of those is a documented way to make it leak or swell.

**Powering the module from 3V3 avoids the problem entirely.** The diode never
forward-biases at that voltage, so no charging current flows, whichever cell
is fitted. The wiring above is therefore already the safe configuration, and
it is one more reason not to reach for `VIN`.

If you have some reason to run it at 5V, then either fit a LIR2032 as the
board intends, or remove the charging resistor.

Sources: [One Transistor](https://www.onetransistor.eu/2019/07/zs042-ds3231-battery-charging-circuit.html),
[Arduino Forum](https://forum.arduino.cc/t/mods-to-ds3231-zs-042-module-for-power-control/1101164)

## Silkscreen and pin order vary

As with the panels, the boards are not all laid out the same way. Some have a
six-pin header on each long edge, mirrored, so the module can be dropped onto
a breadboard either way up. **Read the labels, not the positions** — SDA and
SCL swapped is the single most likely reason for a module that will not
answer, and it does no harm to the chip.

## Building it in

The RTC is compiled out by default. Turn it on with one flag:

```sh
pio run -e gray_rtc_open -t upload     # grayscale panels + RTC
pio run -e esp32dev_rtc -t upload      # colour panels + RTC
```

Those two environments are just `gray` and `esp32dev` with `-DRTC=1`; you can
add the same flag to any environment of your own. `gray_rtc` is the greyscale
one with [passwords](SECURITY.md) on as well, and will not build until they
are set. It costs about **26 KB** of
flash, which is the I²C library plus the driver.

Different pins, if you need them:

```ini
build_flags = -DRTC=1 -DRTC_SDA_PIN=16 -DRTC_SCL_PIN=17
```

A build with `RTC=1` and no module attached is **not an error**. The probe at
boot finds nothing, says so on the console, and the clock free-runs exactly as
it did before. You can wire the module up later without reflashing.

A module whose registers hold an impossible date — a month of 0, a digit
above 9 — is treated like one whose battery ran out: ignored, reported under
`warnings`, and overwritten the next time the clock is set.

## First power-on

```
> rtc
rtc addr=0x68 sda=21 scl=22 present
  battery held; the time is good
  chip    2026-09-10 16:34:12 UTC
  temp    24.75 C
```

A brand-new module has never been set, so expect this instead:

```
  battery lost or never set; the time is not to be believed
```

Set it, and it is kept from then on:

```
> tz chicago
ok tz=CST6CDT,M3.2.0/2,M11.1.0/2
> clock set 16:34
ok clock set 16:34:00
> rtc
  battery held; the time is good
```

With a network, you need not do any of that — the first NTP sync writes the
chip by itself, and says so:

```
[net] time synced: 2026-09-10 16:34:12 CST6CDT,M3.2.0/2,M11.1.0/2
[rtc] written from ntp
```

## If it does not answer

Take the firmware out of the picture:

```sh
pio run -e rtc_probe -t upload -t monitor
```

That scans the whole I²C bus and reads the chip raw, several times a second:

```
scan: found 0x57  (AT24C32 EEPROM)
scan: found 0x68  (DS3231)
status 0x00  oscillator has run continuously
raw 00..06: 12 34 09 03 10 09 26
-> 2026-09-10 09:34:12 UTC   temp 24.75 C
```

| What you see | What it means |
| :--- | :--- |
| `nothing on the bus` | No power, no ground, or SDA and SCL swapped |
| Only `0x57` | The EEPROM is alive but the clock half is not — a faulty board |
| Only `0x68` | Fine. Some boards omit the EEPROM |
| `OSCILLATOR HAS STOPPED` | Never set, or the cell is dead or missing |
| Right date, wrong hour | Expected — the chip holds **UTC**. Set `tz` |

## Why the chip holds UTC

Because DST would otherwise be wrong for half the year on a board with no
network. Storing local time would mean a head unplugged in February and
switched on in July reads an hour out, with nothing available to correct it.
Storing UTC and applying the timezone on the way out gets it right offline,
which is the whole point of fitting a battery.

This is why `tz` works in no-network builds now. It is a setting like any
other, saved with `save`.

## Time source precedence

More than one thing can know the time. They are ranked, and a better source
is never overridden by a worse one:

```
  free-running   ← nothing knows the time; the clock face stays hidden
       ↓
  the RTC        ← read once at boot
       ↓
  set by hand    ← `clock set`; you are correcting it, so you win
       ↓
  NTP            ← a time server answered; also writes the RTC
```

The face is drawn only once something above the first rung has supplied a
time. A head with no network, no RTC and nothing typed in shows eyes without
a clock rather than a clock showing 10:10.

`clock` and the control page both report which one is in charge, and so does
`GET /api/v1/state` as `time.source`.

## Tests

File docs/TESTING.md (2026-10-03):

# Testing it, and the tools that come with it

There is a test suite that runs against a real board over HTTP, a soak harness
for comparing two builds over hours, a load test that catches a board
restarting, and a handful of scripts that build the artwork, the page and the
firmware stamp.

None of it is needed to use the head. It is here because measuring this
project turned up several things that were not what anyone assumed — see
[HTTP_LATENCY.md](HTTP_LATENCY.md) for where that led.

## Testing it

[`tools/test_api.py`](../tools/test_api.py) exercises a running board over HTTP.
Real hardware, because that is where the interesting failures are — a handler
that works alone but starves the render loop, a value that survives a round
trip but not a reboot, a verb that returns the wrong status only when the body
is malformed.

```sh
uv run tools/test_api.py --host frank.local
uv run tools/test_api.py --host 192.168.1.50 --token ...
uv run tools/test_api.py --host frank.local --user frank --password ...
```

[`tools/soak.py`](../tools/soak.py) is for comparing two builds over hours. It
flashes and measures both in every round, reversing the order each time, so
both see the same radio — measuring one build and then the other compares
their weather, which was enough to invert a conclusion twice before this
existed. See [docs/HTTP_LATENCY.md](HTTP_LATENCY.md).

```sh
uv run tools/soak.py --hours 3 --a=-DCLOCK=1 --b=-DCLOCK=0
```

The `=` matters: written as `--a -DCLOCK=1`, the flag would be taken for
another option and the command refused.

Each row of the CSV carries the signal strength at the time it was taken, and
each round prints it. That column is there because the radio is the variable
that moves on its own: the first comparison run on this project concluded a
change was catastrophically worse, while RSSI drifted from −48 to −56 dBm
underneath it. Timings without the conditions they were taken in are not
evidence.

[`tools/load_test.py`](../tools/load_test.py) is for power. It runs the suite
against one board over and over and reports every time the board restarted,
and why. A board on a marginal supply browns out when its current steps up,
and the biggest step it takes is the eyes coming back to full speed after a
pause — which an eye-file upload makes, stalling both cores while flash is
written. So pass one through to the suite:

```sh
uv run tools/load_test.py --host frank.local --minutes 45 --port COM3 \
    -- --eye-file dist/eyes/dragon.bin
```

It notices a restart two ways. Between runs, an uptime that has fallen behind
the clock means the board restarted, and its warnings then name the reason —
a brownout, a crash, a watchdog. With `--port` it also watches the serial
port, without resetting the board, and prints what led up to each restart.
Everything after `--` goes to `test_api.py` unchanged; like the suite, it
leaves the eye file loaded. The numbers in
[Frame rate](FRAME_RATE.md#brownouts-and-the-cpu-at-160-mhz) came from it.

It reports latency as percentiles and a histogram rather than an average,
because on this board the tail is the interesting part — a mean of 60 ms hides
a request that took eight seconds. `--latency N` skips the tests and times N
requests per endpoint instead, which is how you tell whether a change helped:

```sh
uv run tools/test_api.py --host frank.local --latency 20
```

`--decompose N` goes one level further and splits each request into its
handshake, its wait, and its transfer, using a raw socket because `urllib`
returns a single number for the whole exchange:

```sh
uv run tools/test_api.py --host frank.local --decompose 200
```

This is what finally explained where the time goes, and the answer was not the
firmware: on a link losing 6% of its packets, the TCP handshake alone was a
third of a typical request, and every outlier was a retransmission timer. If
the board feels slow, run this before changing any code — see
[docs/HTTP_LATENCY.md](HTTP_LATENCY.md).

Around 200 checks across every endpoint: round trips, range limits, the 400 /
404 / 405 boundaries, malformed bodies, CORS preflight, credentials, brightness
and its fades, and a burst of gaze updates of the kind dragging the aim pad produces — which
checks both that the last position is the one that sticks and that the eyes
keep rendering while it happens.

It adapts to the firmware it finds: `GET /api/v1/info` says which features are
compiled in, so a build without an RTC or without authentication has those
groups skipped rather than failed. It captures the board's state at the start
and puts it back at the end. Nothing reboots the board or writes flash unless
you pass `--wifi`, `--settings` or `--restart`. The same goes for `--eye-file
dist/eyes/NAME.bin`, which fills the [eye slot](EYE_FILES.md), damages an
upload on purpose, and removes it again. The uploads the board refuses
*before* erasing anything are tested on every run, and checked to have left
the slot alone.

`--settings` saves, then changes each saved setting through the API to the
value it already has, and checks that every one marks the settings unsaved —
otherwise the page would say "saved" about a change a restart loses.

`--restart` restarts the board twice: once to move the CPU speed to its other
setting, and once to move it back. It checks that the new speed took, and that
a restart the board was asked for leaves no warning behind.

A group called *refusing bad input* sends the API the kinds of values it
once accepted wrongly: out-of-range numbers that a narrowing cast used to
wrap into range, times with trailing junk, fields of the wrong type, and
one bad field beside a good one, which must leave the good one unapplied
too. None of it changes the board, including the WiFi cases, each of which
would reboot it if it were ever accepted.

A group called *taking a request* sends four requests `urllib` will not
send:

- a head too large, which must get `431`;
- a body too large, which must get `413`;
- a broken `Content-Length`, which must get `400`;
- a request that never finishes arriving, which must be dropped. While it
  waits, the frame rate is checked to show the eyes kept moving.

That last one costs five seconds a run.

It also reports any request that took over a second, because on this board a
slow request is a stalled render loop.

## The tools

[`tools/ota.py`](../tools/ota.py) uploads firmware over WiFi and verifies it
against the running device,
[`tools/gen_eyes.py`](../tools/gen_eyes.py) converts the artwork,
[`tools/make_eye.py`](../tools/make_eye.py) turns a design into an
[eye file](EYE_FILES.md),
[`tools/gen_page.py`](../tools/gen_page.py) compresses the control page into the
firmware, [`tools/git_rev.py`](../tools/git_rev.py) stamps the build with its
commit, and [`tools/nvs_backup.py`](../tools/nvs_backup.py) saves everything the
board remembers to a JSON file and puts it back — including the WiFi network,
which the radio keeps in a namespace of its own. That one is USB only, and
[Configuring](CONFIG.md) explains what is in there. [`tools/test_api.py`](../tools/test_api.py),
[`tools/soak.py`](../tools/soak.py) and [`tools/load_test.py`](../tools/load_test.py) are described under
[Testing it](#testing-it).

All are type-annotated: every parameter, every return type, and every local
at the point it is introduced. A count of bare assignments in these files is
not a count of missing types, for three reasons. Reassignments carry no
annotation, which is what [PEP 526](https://peps.python.org/pep-0526/) asks
for — the name is declared once, not at every binding. Tuple unpacking
(`code, raw = api.raw(...)`) and the targets of `with` and `for` cannot carry
one syntactically; every such binding here takes its type from an annotated
call or a literal, and where neither applies — the fields `struct.unpack`
returns, say — the names are declared on their own lines just above. And `Any` appears where it is honest to — decoded JSON and
parsed NVS values really are of unknown type, and claiming otherwise would
be worse than saying so.

### Running them

The tools run on Python 3.14 through [uv](https://docs.astral.sh/uv/), which
the repository is set up for. `pyproject.toml` names the three packages they
need — Pillow for `gen_eyes.py`, pyserial for `load_test.py --port`, esptool
for `nvs_backup.py` — and `uv.lock` pins them. `uv run tools/<script>.py`
fetches Python and the packages the first time, and runs the script; nothing
is installed anywhere else.

uv keeps that environment in `.venv` inside the repository unless
`UV_PROJECT_ENVIRONMENT` points elsewhere. Point it elsewhere if the
repository lives in a synced folder — Google Drive, Dropbox, OneDrive — or
the environment is uploaded along with it:

```sh
export UV_PROJECT_ENVIRONMENT=~/.cache/uv-envs/creeper-eyes
```

(`$env:UV_PROJECT_ENVIRONMENT = "..."` in PowerShell.)

Four scripts are not run that way. [`tools/git_rev.py`](../tools/git_rev.py)
and [`tools/gen_page.py`](../tools/gen_page.py) are PlatformIO build hooks, run
by whatever Python PlatformIO itself runs on — 3.14 for a
`uv tool install platformio`, 3.11 inside the VS Code extension — so they use
the standard library only, and no syntax newer than 3.11.
[`hardware/gen_board.py`](../hardware/gen_board.py) and
`hardware/make_outputs.py` need KiCad's `pcbnew` and run on the Python inside
KiCad; the [hardware README](../hardware/README.md) says how.

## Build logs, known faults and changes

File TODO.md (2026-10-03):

# TODO

Things worth doing, not yet started: features that do not exist and bugs
that have not been fixed. Nothing here has been acted on. Where a section
carries measurements, they are the ones that shaped the entry rather than
results from working code. An entry may record a decision taken about it
— including a decision not to build it, and why — without any of it
having been written.

## Code quality: a review on 2026-10-02

A review of the hand-written code for how it reads, rather than for bugs:
whether it is consistent, whether it can be followed, whether the comments
are earning their place, whether things are well named, and whether the
files divide the work sensibly. Most of what it found is in `src/main.cpp`.
At 3,400 lines it is the one file that ignores the pattern the rest of the
firmware follows: a module owns its state, and everything else reaches that
state through functions, as `dimmer.cpp` and `sleepmode.cpp` do. Entries
leave this list as they are done.

### Bugs it found on the way

- With the pupil turned off, `PUPIL_OFF_SCALE` is applied before `frame()`
  remaps the scale. The arithmetic says a dot about 5 px across may remain.
  This hasn't been checked on a panel.
- The `hardware/*/images/schematic.pdf` files still say rev A. The
  schematics themselves say rev B now; the PDFs follow the next time
  `make_outputs.py` runs in KiCad.

**A decision rather than a bug.** A `NETWORK=1, COMMANDS=0` build has no
BOOT button, so no factory reset, which is the only way back into a board
whose password has been forgotten. `docs/CONFIG.md` says so on purpose:
`COMMANDS` is the console *and* the button. The alternative is to compile
the button whenever the board is controllable at all.

### Consistency and naming

- **Names to change:**
  - The five artwork globals (`upper`, `lower`, `iris`, `polar`, `sclera`)
    become one read-only `EyeArtwork`.
  - `timeSynced` → `timeKnown()`, which its own comment says it means.
- **One feature, several names.** The address cards have five names across
  C, the API, the console and the page. Dilation is "width" on the page.

### Reorganising

In this order, building every environment and running the API suite after
each step:

1. **Have the console read through `state.h` too.** It changes things only
   through `state.h` now, but `status`, the eye list, `clock`, `pupil`, `cpu`
   and `swap` still read `main.cpp`'s globals directly. `DeviceState` needs
   the few fields it lacks: the startle phase, the core-0 idle gap and the
   sender's rests.
2. **Move the build switches still in `main.cpp` into `config.h`.** Put the
   pins in a `pins.h` that the three panel diagnostics share, instead of
   keeping their own copies.
3. **Move the console into `console.cpp`**, with a command table that
   drives both dispatch and `help`, replacing the 515-line if/else chain.
   Move the BOOT button into `button.cpp`.
4. **Split the rest of `main.cpp`, one module at a time:**
   - `watchdog`;
   - `designs`, along with one shared definition of the eye-file geometry,
     which is written in five places now;
   - `display` and `framesend`;
   - `clockface` and `splash`;
   - `settings`, with one constant for the NVS namespace that
     `credentials.cpp` shares today only because both spell it "creeper";
   - `state.cpp`, dropping `state.h`'s argument against this split.
5. **Last, and riskiest: `motion` and `render`.**
   - Make the iris walk non-blocking, so `loop()` shows the program's real
     control flow; today a recursive `walkIris()` blocks there for 10 s.
   - Break the 340-line `frame()` into the steps it performs.
   - Compare frame rate and latency before and after.

Smaller moves that can come at any point:

- Request intake (`arrival()`, `routeOf()`, `turnAway()`, the
  `handleClient()` override) moves out of `auth.cpp` into a
  `webserver.cpp`.
- web.cpp's declarations move out of `net.h` into a `web.h`.
- **Adding an eye design** takes four edits in two files; one list
  generated by `gen_eyes.py` would make it one.
- **Helpers written several times:** the control-character check (three
  copies), the network-status name (three), and the date and time
  formatting (nine).
- **`api.cpp`'s route table** repeats the same four lines for each of 23
  paths, and six GET handlers differ in one call.
- **`index.html`'s script** is ordered by history rather than by card, and
  shows and hides the banner differently from everything else.
- **`favicon.h`** is included by no C file; `gen_page.py` reads it with a
  regex. Two `.svg` files in `data/` would replace it.
- **`rtcRead()`** decodes the registers in two interleaved passes.
- **`LOCKED`** is a macro that hides a declaration.
- **`tools/test_api.py` becomes three files:** the HTTP client, which
  `load_test.py` and `soak.py` already import and which `ota.py` should use
  too; the latency tools; and the tests, each with one signature and driven
  by a table.
- **In `hardware/`,** `make_outputs.py` passes its state through module
  globals, and `gen_board.py`'s `build_board()` is 260 lines long.

## Online firmware updates

**Not being built, as of 2026-09-22.** A judgement call rather than a blocked
one: the head works, `tools/ota.py` updates it from the author's machine in
under two minutes, and everything below is a large amount of new surface — a
second way into the device, credentials that have to move before it can be
used at all, and a failure mode whose worst case is a brick in a sealed head
— in exchange for convenience the one person currently updating a head does
not need. The reasoning below is kept because it is the expensive part and it
does not spoil: picking this up again is a decision, not a fresh
investigation.

A head that can update itself, rather than one that waits for somebody with a
checkout of this repository and a working PlatformIO install.

Today's over-the-air update still starts on a computer: `pio run -t upload` or
[`tools/ota.py`](tools/ota.py) pushes a binary the operator already has. See
[Networking](docs/NETWORK.md) for what exists now.

### Three goals, which are not the same size

1. **No PlatformIO and no checkout needed to update a head.**
2. **The head fetches new firmware itself, from the internet.**
3. **The head notices new firmware exists and says so.**

The actual pain is (1). (2) and (3) are considerably larger, and only (2)
needs GitHub at all. Doing them in order means each step is useful on its own
and none of them blocks on the one after it.

### What the hardware already gives us

`partitions.csv` has two app slots and an `otadata` partition (and, since
[eye files](docs/EYE_FILES.md), an eye slot beside them):

| partition | offset | size |
| :-- | :-- | :-- |
| `otadata` | `0xE000` | 8 KB |
| `app0` | `0x10000` | 1.81 MB |
| `app1` | `0x1E0000` | 1.81 MB |

`gray_rtc` builds to about 1.25 MB now that it carries one eye design, so
there is roughly 600 KB of headroom in a slot — enough for TLS if it comes to
that, but not a lot.

Rollback is compiled into the core the project already builds against:
`CONFIG_BOOTLOADER_APP_ROLLBACK_ENABLE=y` and `CONFIG_APP_ROLLBACK_ENABLE=y`.
A freshly flashed slot boots in `ESP_OTA_IMG_PENDING_VERIFY`, and
`esp32-hal-misc.c` confirms it automatically at boot — *unless* the weak
`verifyRollbackLater()` is overridden to return true, at which point
confirming becomes ours to do with
`esp_ota_mark_app_valid_cancel_rollback()`. So the mechanism is there and
opting into it is one function.

### Two prerequisites that are specific to this project

Neither is about networking, and both are the real work.

**The build matrix.** There are sixteen environments. A head needs the binary
matching its panel type, its RTC and its auth flags, and a wrong pick is a
brick. The device does know what it is — `GET /api/v1/info` already reports
which features are compiled in — so it can ask for a named variant. But it
means publishing roughly ten binaries per release, and it means the naming
scheme becomes an interface that cannot casually change.

*Decided, 2026-09-22: publish two.* `gray_rtc` — greyscale panels, an RTC,
`AUTH_HTTP` / `AUTH_TOKEN` / `AUTH_HOST_CHECK`, which is what the author's
head runs — and the same build with colour panels, which does not exist as an
environment yet: `esp32dev_rtc` is colour with an RTC but carries none of the
auth flags, so the twin is either that environment with the three flags added
or a new one beside it. One `-DUSE_SSD1327` apart, and the device already
knows which of the two it is, so variant matching stops being a problem worth
designing for. Everything else — no RTC, no authentication, the `_open`
builds, the diagnostics — is built from source by whoever wants it and is not
published at all.

The cost of that choice is that the published pair cannot be the binaries the
author builds today, for the reason that follows.

**Credentials are compiled in.** `gray_rtc` requires `AUTH_USER`, `AUTH_PASS`
and `AUTH_TOKEN_VALUE` in `include/secrets.h` and refuses to build without
them. A published binary cannot contain anybody's secrets, so a generic
release binary arrives with no built-in credentials at all.

`credBegin()` prefers NVS over the built-ins and NVS survives an OTA, so a
board whose credentials are stored is fine. The author's board is not: it
reports `stored: false` for all four and runs on the built-ins. So online
updates need, first:

- a way to move built-in credentials into NVS deliberately, and
- an `AUTH_HTTP=1` build that tolerates having no built-ins, refusing access
  rather than allowing it when NVS is also empty.

So the two published variants are `gray_rtc` and its colour twin *built
without credentials*, which is a slightly different firmware from the one the
author runs — and on the author's own head the order matters. The credentials
have to reach NVS **before** the first credential-less binary is flashed onto
it, or that head comes up with no way in: no built-ins, an empty store, and
`PUT /api/v1/credentials` sitting behind the very authentication that now has
nothing to check against. Once they are stored the published binary and the
private one behave identically, and the author is then running the thing
everybody else downloads, which is the best test it can get.

`WIFI_SSID` / `WIFI_PASS` need the same move and are the safe case: a head
with no stored network opens the setup portal and shows a join code, so it can
be recovered without being opened.

### The plan, in the order the steps are worth doing

**Step 1 — upload a `.bin` from the control page.** Browser to head, over the
LAN. No internet, no TLS, no certificate authority, no GitHub, no manifest,
and no variant matching: the operator picks the file, so "which binary" is
answered by the person who knows. This alone retires goal (1), which is the
only goal anybody is actually blocked by today.

**Step 2 — fetch a URL typed into the control page.** The same flow with the
download moved onto the device. Still no version checking and still no
GitHub; the operator is still choosing.

**Step 3 — a signed manifest.** A small JSON file naming the current version,
a URL per variant, and a hash. The head compares against its own
`FIRMWARE_VERSION`, and offers rather than takes.

### On GitHub Releases specifically

It is a reasonable instinct: free, versioned, already where the code lives,
release notes for nothing. Three things bite.

- **HTTPS is mandatory**, and an asset download redirects to a different host,
  so the device must follow a 302 *and* complete a second handshake against a
  different chain. Root CAs get pinned into firmware, and when GitHub rotates
  them every head in the field loses its update path permanently, silently,
  years later. This is the way this feature usually breaks.
- **Rate limits.** Sixty requests an hour per IP unauthenticated. Fine for a
  manual check, bad for polling, and worse for several heads behind one NAT.
- **TLS costs.** mbedTLS wants tens of KB of heap during the handshake,
  alongside the panel canvases and the web server, plus a couple of hundred KB
  of flash against that 600 KB of headroom.

**Signing the binary makes most of that go away.** With a public key baked
into the firmware and a signature checked before the slot is marked bootable,
the transport stops needing to be trusted: fetch over plain HTTP, drop
mbedTLS, and the certificate-expiry time bomb disappears with it. GitHub then
becomes an ordinary file host and could be swapped for any other. Which
algorithm and which implementation is an open question, not a decision.

### Non-negotiable once a binary can arrive without a cable

- **Verify before marking the slot bootable** — hash at minimum, signature
  preferably — rather than after.
- **Confirm on evidence, not on booting.** Override `verifyRollbackLater()`
  and call `esp_ota_mark_app_valid_cancel_rollback()` only once the new
  firmware has joined WiFi and served a page. A firmware that boots but cannot
  be reached is indistinguishable from a brick in a sealed head, and not
  opening a sealed head again is the premise of the project.
- **Never update unasked.** A prop that reboots itself in the middle of
  Halloween is a fault, whatever the changelog said. The same reasoning
  already sets `SLEEP_ENABLED` to 0 by default.

### Open questions

- ~~Which variants are worth publishing~~ — two, above. What they are *called*
  is still open, and it is the half that becomes an interface: a name
  published once has to keep meaning the same thing.
- Whether step 3 is wanted at all, or whether step 2 is where this should
  stop.
- Whether an update should be refused while the clock says it is near or
  inside the sleep window, on the grounds that nobody is watching to see it
  fail.

## A light sensor for automatic brightness

The [dimmer](docs/BRIGHTNESS.md) exists; what it lacks is a reason to move by
itself. A light-dependent resistor and a fixed resistor, as a divider on one of
the DevKit's input-only pins, would let the eyes turn themselves down in a dark
room and up in a bright one.

- **Pins.** `D34`, `D35`, `VP` (GPIO36) and `VN` (GPIO39) are all unused on
  the carrier board and are all ADC1, which keeps working with WiFi up (ADC2
  does not). On a rev A or rev B board it is three jumpers; a later revision
  could carry a footprint for it.
- **Where it plugs in.** Another factor in `dimmerPoll()`'s target, beside
  sleep's: the setting stays what the person chose, and the sensor scales it.
- **Open questions.** Where the sensor sits so it sees the room and not the
  eyes' own glow; how much smoothing, so a passing shadow does not flicker the
  eyes; and whether it should only ever dim, never brighten past the setting.

## frank-dev's watchdog: found and fixed, not yet proven

frank-dev, the colour board, restarted after the task watchdog on 2026-09-25
and again on 2026-09-28, with nothing testing it; the second time the report
blamed `panels`, the frame sender. The cause was the sender's rest. It
stepped aside for one tick a second, which anything else on core 0 could take
before the idle task did, and five lost in a row is the watchdog — see
[Frame rate](docs/FRAME_RATE.md#drawing-and-sending-at-once). Since 65f5d2f
the sender rests until the idle task has actually run.

- **Measured, not waited for.** `status` now carries `idle0gap`, the longest
  core 0 has gone without its idle task. Before the fix it reached 3.0 s in six
  minutes on a quiet network; with it, it held at 1.03 s through 13 minutes
  quiet and 11 of `tools/load_test.py`.
- **What is left is time.** Two resets in three days is too rare to rule out
  in half an hour. A week on frank-dev without one, with `idle0gap` near a
  second, would settle it, and then this entry can go.
- **If it comes back,** `idle0gap` says how close core 0 has come. A gap well
  past a second with the sender resting properly would mean something else
  is keeping core 0 busy, and the report would then name that task rather
  than `panels`.

## The panel bus speed as a setting

The CPU speed is a setting now; the speed of the SPI bus each panel is driven
at is still a build option, `SSD1351_SPI_HZ` or `SSD1327_SPI_HZ`. It was
discussed beside the CPU speed and not built. Lowering it is the cure for a
panel that flickers or speckles, so as a setting it would let a sealed head be
turned down without a rebuild. It would belong on the same card as the CPU
speed.

## Three pictures

The only photograph in the repository is a screenshot, and it is out of
date. Each of these has a place already waiting for it; none is written
yet.

- **`docs/images/webui.png`, retaken.** The control page as it was on
  2026-09-10, before the **flip** buttons, the eye-file controls, the
  brightness slider and the warnings box joined it. It is the first thing the README shows and the first thing in
  [Driving it](docs/CONTROL.md), so it is the picture most people will
  compare against what they see. Same file name, same two places; nothing
  else references it.

- **Frank in action.** A photo of the head with the eyes running, for the
  top of the README. Today the README opens with the control page, which
  shows what the project *does to* the eyes rather than what they look
  like; the head itself is what anyone landing on the page wants to see
  first, and the screenshot can move down to the "Takes direction" line it
  illustrates. Dim room, eyes lit, ideally mid-glance so the gaze reads as
  a gaze and not a stare.

- **The ESP32 on a breadboard, wired to both panels.** For
  [Wiring](docs/WIRING.md), somewhere between "Connections" and "Order of
  assembly". The table there is complete and the prose is careful, but
  fourteen wires is the point at which a photo says in one look what the
  table says in fourteen rows — which side of the module the panels sit,
  where the rails are used, how the shared lines are daisy-chained. Taken
  from above, in enough light to follow a wire from pin to pin.

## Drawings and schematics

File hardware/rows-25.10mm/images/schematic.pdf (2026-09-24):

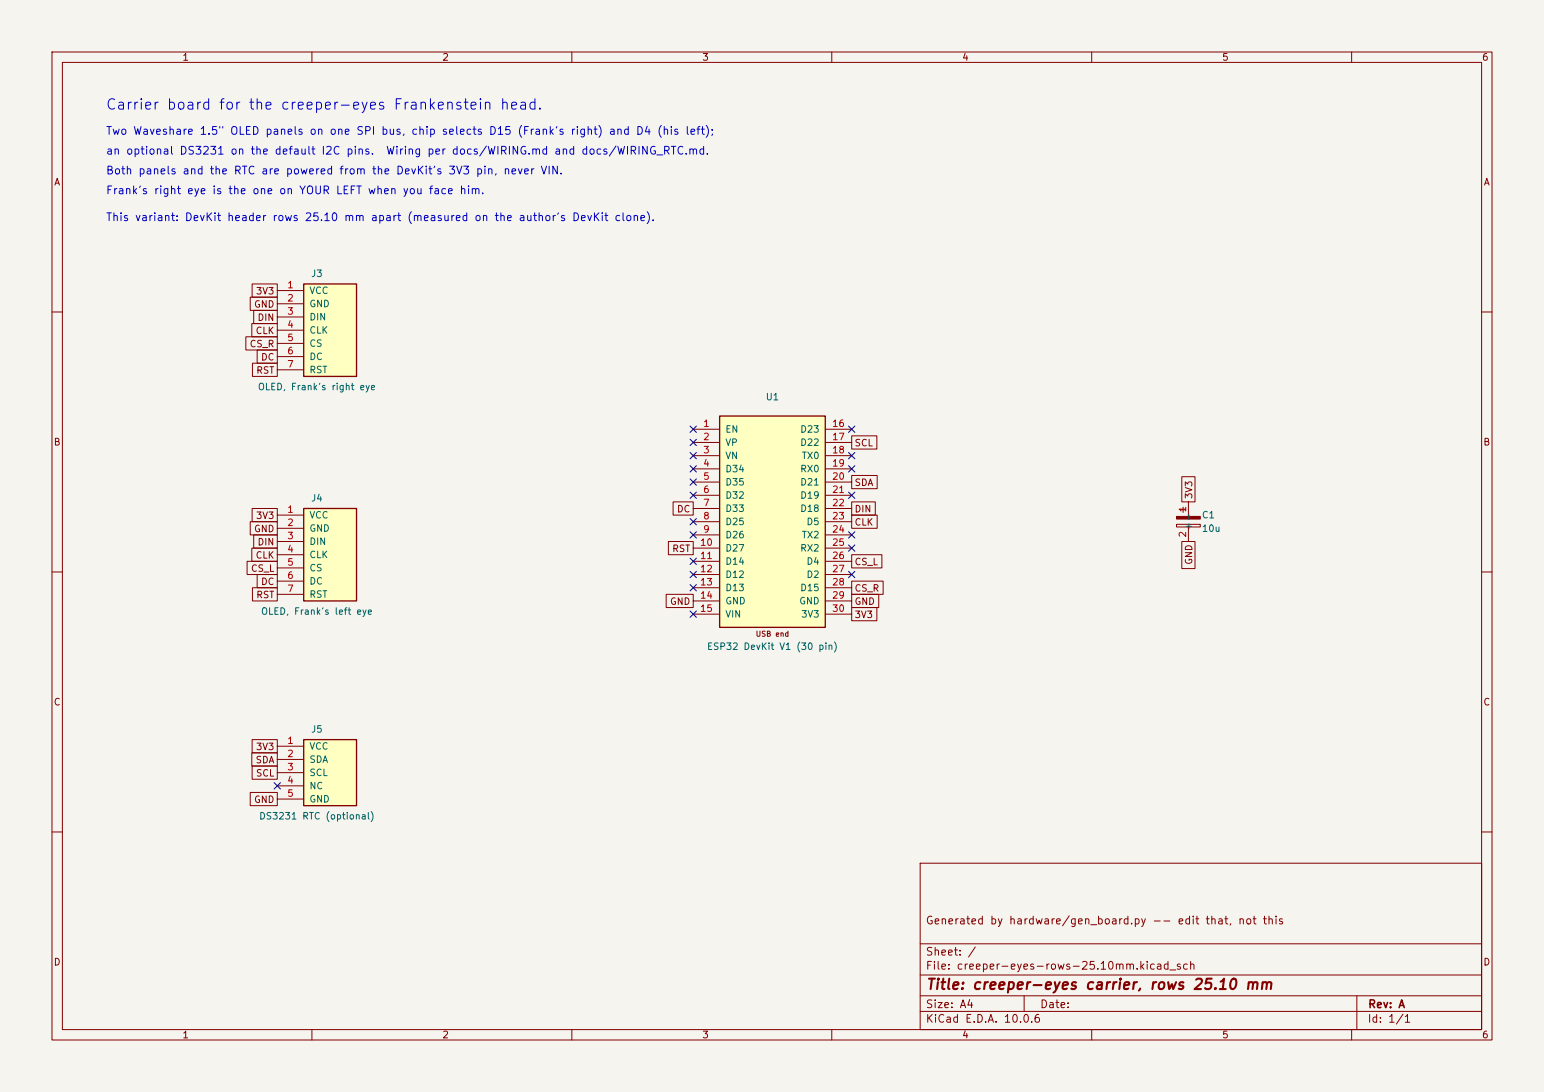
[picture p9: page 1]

Carrier board for the creeper-eyes Frankenstein head.

Two Waveshare 1.5" OLED panels on one SPI bus, chip selects D15 (Frank's right) and D4 (his left); an optional DS3231 on the default I2C pins. Wiring per docs/WIRING.md and docs/WIRING_RTC.md.

SDA SCL DC Both panels and the RTC are powered from the DevKit's 3V3 pin, never VIN.
Frank's right eye is the one on YOUR LEFT when you face him.

This variant: DevKit header rows 25.10 mm apart (measured on the author's DevKit clone).

Generated by hardware/gen_board.py -- edit that, not this

Sheet: /
File: creeper-eyes-rows-25.10mm.kicad_sch
Title: creeper-eyes carrier, rows 25.10 mm

Size: A4 | Rev: A
KiCad E.D.A. 10.0.6 | Id: 1/1

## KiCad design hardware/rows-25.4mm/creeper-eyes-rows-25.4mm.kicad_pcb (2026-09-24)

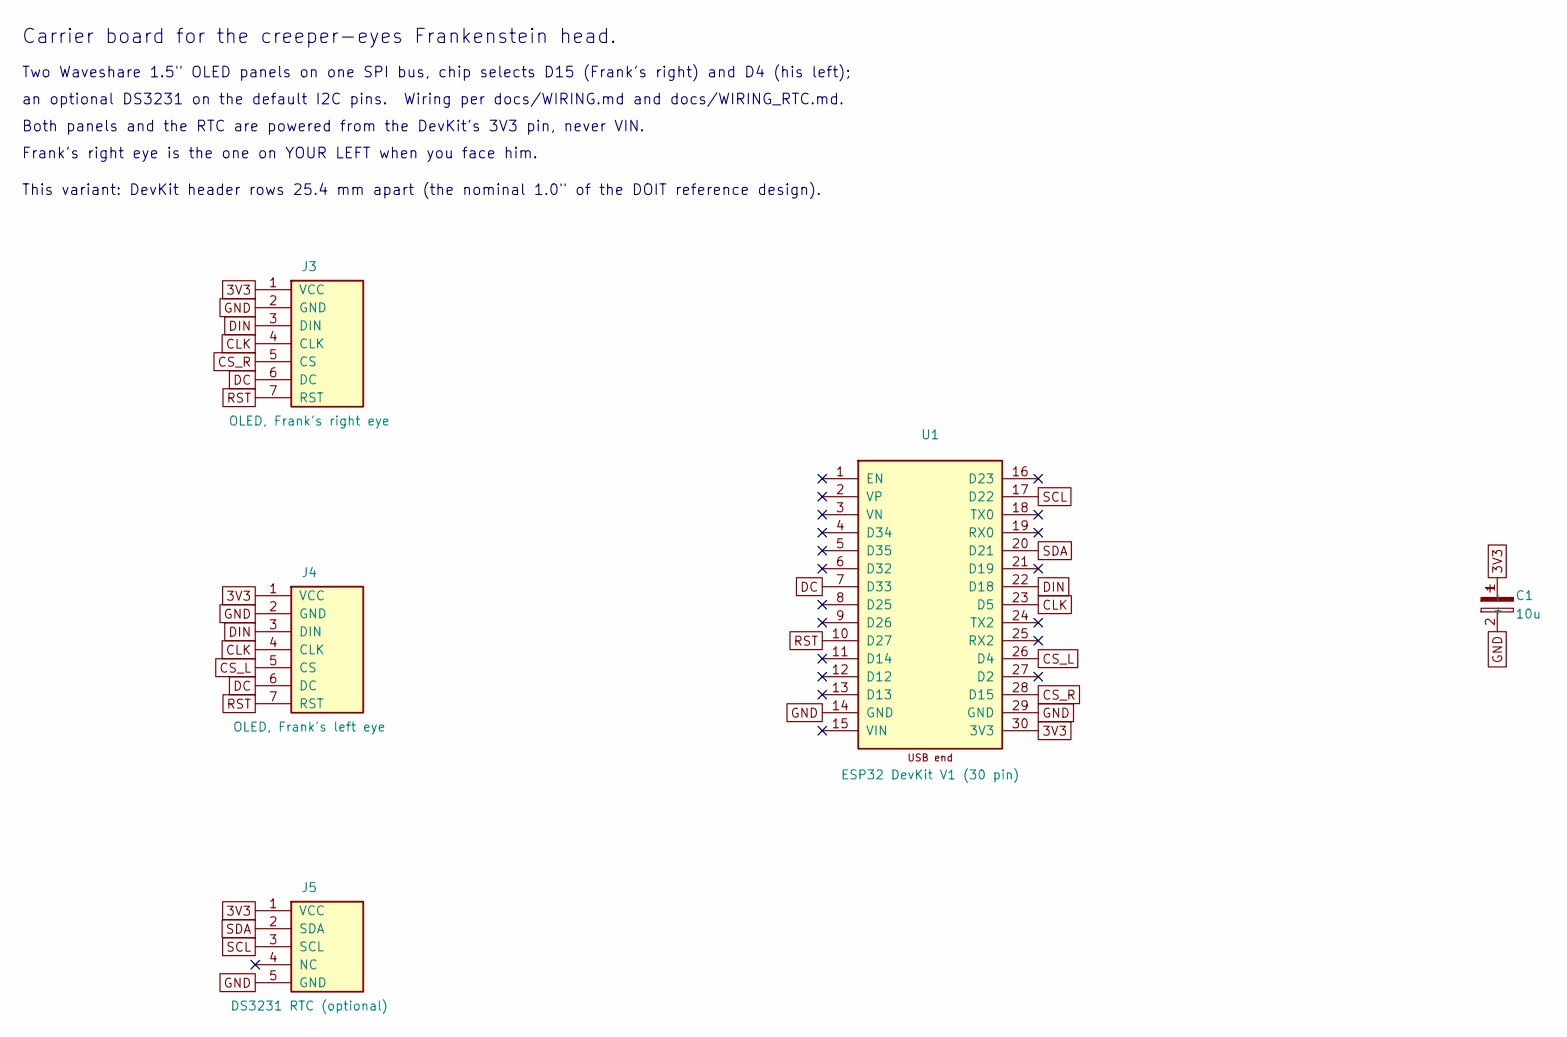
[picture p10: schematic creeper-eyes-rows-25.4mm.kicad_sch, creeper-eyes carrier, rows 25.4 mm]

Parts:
C1: 10u; CP_Radial_D5.0mm_P2.00mm
J3: OLED, Frank's right eye; PinHeader_1x07_P2.54mm_Vertical
J4: OLED, Frank's left eye; PinHeader_1x07_P2.54mm_Vertical
J5: DS3231 RTC (optional); PinHeader_1x05_P2.54mm_Vertical
U1: ESP32 DevKit V1 (30 pin); ESP32_DevKit_V1_30pin

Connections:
3V3: C1.1 (+), J3.1 (VCC), J4.1 (VCC), J5.1 (VCC), U1.30 (3V3)
CLK: J3.4 (CLK), J4.4 (CLK), U1.23 (D5)
CS_L: J4.5 (CS), U1.26 (D4)
CS_R: J3.5 (CS), U1.28 (D15)
DC: J3.6 (DC), J4.6 (DC), U1.7 (D33)
DIN: J3.3 (DIN), J4.3 (DIN), U1.22 (D18)
GND: C1.2 (-), J3.2 (GND), J4.2 (GND), J5.5 (GND), U1.14 (GND), U1.29 (GND)
RST: J3.7 (RST), J4.7 (RST), U1.10 (D27)
SCL: J5.3 (SCL), U1.17 (D22)
SDA: J5.2 (SDA), U1.20 (D21)

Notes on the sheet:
Carrier board for the creeper-eyes Frankenstein head.
Two Waveshare 1.5" OLED panels on one SPI bus, chip selects D15 (Frank's right) and D4 (his left);
an optional DS3231 on the default I2C pins. Wiring per docs/WIRING.md and docs/WIRING_RTC.md.
Both panels and the RTC are powered from the DevKit's 3V3 pin, never VIN.
Frank's right eye is the one on YOUR LEFT when you face him.
This variant: DevKit header rows 25.4 mm apart (the nominal 1.0" of the DOIT reference design).

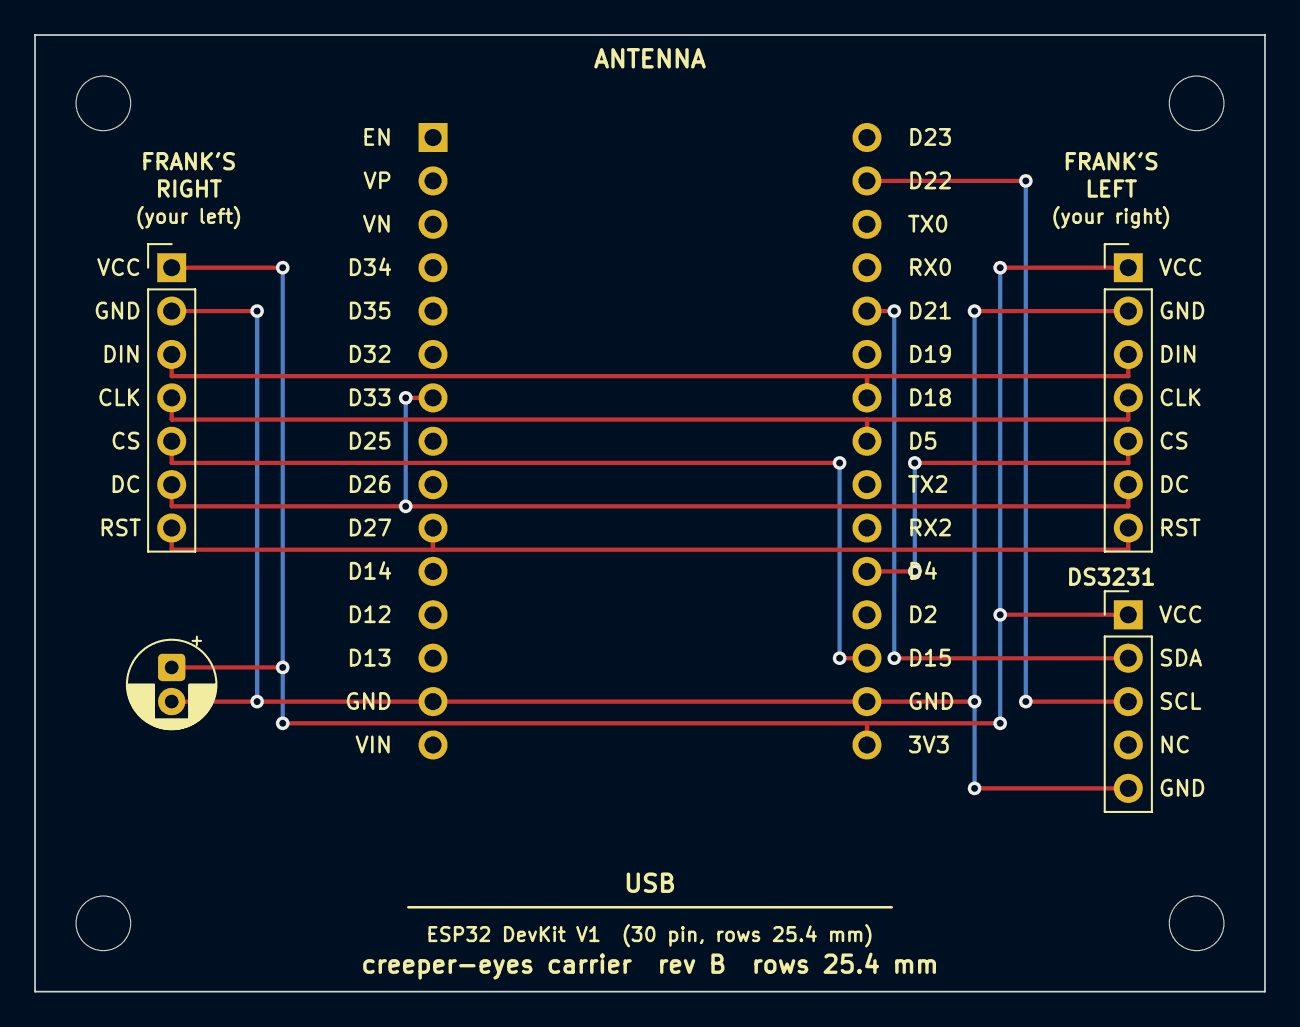
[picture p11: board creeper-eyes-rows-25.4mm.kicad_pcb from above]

Board: 2 copper layers, 72.0 x 56.0 mm, 9 parts (0 on the bottom side), 10 nets.

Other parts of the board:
H1, H2, H3, H4: M3; MountingHole_3.2mm_M3

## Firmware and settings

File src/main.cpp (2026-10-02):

//--------------------------------------------------------------------------
// 2018 Modified by Laurent Moll for Uncanny Eyes costume
// https://www.hackster.io/projects/376a13/
// Based on Adafruit code  - Adafruit header below:
//
// Uncanny eyes for PJRC Teensy 3.1 with Adafruit 1.5" OLED (product #1431)
// or 1.44" TFT LCD (#2088).  This uses Teensy-3.1-specific features and
// WILL NOT work on normal Arduino or other boards!  Use 72 MHz (Optimized)
// board speed -- OLED does not work at 96 MHz.
//
// Adafruit invests time and resources providing this open source code,
// please support Adafruit and open-source hardware by purchasing products
// from Adafruit!
//
// Written by Phil Burgess / Paint Your Dragon for Adafruit Industries.
// MIT license.  SPI FIFO insight from Paul Stoffregen's ILI9341_t3 library.
// Inspired by David Boccabella's (Marcwolf) hybrid servo/OLED eye concept.
//--------------------------------------------------------------------------

#include "config.h"
#include "console.h"
#include "state.h"
#include "display.h"
#include "net.h"
#include "sleepmode.h"
#include "credentials.h"
#include "rtc.h"
#include "timekeeping.h"
#include "eyestore.h"
#include "dimmer.h"
#include "health.h"
#include "nvsread.h"
#include "parse.h"

#include <Adafruit_GFX.h>   // Core graphics lib for Adafruit displays
#include <Preferences.h>    // NVS-backed settings, part of the ESP32 core
#if NETWORK
#include <WiFi.h>
#endif
#include <SPI.h>
#include <esp_freertos_hooks.h> // the tick hook behind wdtClue

// Which designs are built in -- see include/eyes_config.h.  The headers are
// modified from Adafruit's originals so that several can be included at once,
// each set of symbols carrying its own suffix.
#include "eyes_config.h"

#if EYE_DEFAULT
#include "defaultEye.h" // Standard human-ish hazel eye
#endif
#if EYE_NEWT
#include "newtEye.h" // Eye of newt
#endif
#if EYE_ANIME
#include "eyes/anime.h" // Large violet anime iris
#endif
#if EYE_BIGBLUE
#include "eyes/bigBlue.h" // Pale blue, heavy limbal ring
#endif
#if EYE_BLUEFLAME1
#include "eyes/blueFlame1.h" // Blue flame ring on black
#endif
#if EYE_BLUEFLAME2
#include "eyes/blueFlame2.h" // Blue flame, slit pupil
#endif
#if EYE_BROWN
#include "eyes/brown.h" // Warm brown, veined sclera
#endif
#if EYE_CAT
#include "eyes/cat.h" // Yellow cat eye, slit pupil
#endif
#if EYE_DEMON
#include "eyes/demon.h" // Red demon, slit pupil
#endif
#if EYE_DOE
#include "eyes/doe.h" // Soft brown doe eye
#endif
#if EYE_DOOMRED
#include "eyes/doomRed.h" // Red on white, cartoon
#endif
#if EYE_DOOMSPIRAL
#include "eyes/doomSpiral.h" // Red spiral
#endif
#if EYE_DRAGON
#include "eyes/dragon.h" // Fiery dragon, slit pupil
#endif
#if EYE_FIREBOX
#include "eyes/firebox.h" // Orange fire ring
#endif
#if EYE_FISH
#include "eyes/fish.h" // Pale fish eye, no eyelids
#endif
#if EYE_FIZZGIG
#include "eyes/fizzgig.h" // Orange fizzgig
#endif
#if EYE_FLAME
#include "eyes/flame.h" // Flame iris, slit pupil
#endif
#if EYE_HAZEL
#include "eyes/hazel.h" // Hazel, veined sclera
#endif
#if EYE_HYPNORED
#include "eyes/hypnoRed.h" // Red hypnotic rings
#endif
#if EYE_LEOPARD
#include "eyes/leopard.h" // Golden leopard
#endif
#if EYE_NEWT2
#include "eyes/newt2.h" // Eye of newt (TeensyEyes)
#endif
#if EYE_SKULL
#include "eyes/skull.h" // Red on bone, no eyelids
#endif
#if EYE_SNAKEGREEN
#include "eyes/snakeGreen.h" // Green snake, slit pupil
#endif
#if EYE_SPIKES
#include "eyes/spikes.h" // Geometric spikes
#endif
#if EYE_TOONSTRIPE
#include "eyes/toonstripe.h" // Striped cartoon, no eyelids
#endif

// The renderer reads the artwork through these.  They are pointers TO const
// data, not const pointers, so a whole design can be swapped at runtime.
// Swap between frames, never mid-render: drawEye() reads all five as it
// scans, so changing them under it would tear one frame.
const uint16_t (*sclera)[SCLERA_WIDTH];
const uint8_t (*upper)[SCREEN_WIDTH];
const uint8_t (*lower)[SCREEN_WIDTH];
const uint16_t (*polar)[IRIS_WIDTH];
const uint16_t (*iris)[IRIS_MAP_WIDTH];

// Registry of the designs compiled in.  Order here is the order the console
// reports and indexes them by.
struct EyeDesign {
  const char *name;
  const uint16_t (*sclera)[SCLERA_WIDTH];
  const uint8_t (*upper)[SCREEN_WIDTH];
  const uint8_t (*lower)[SCREEN_WIDTH];
  const uint16_t (*polar)[IRIS_WIDTH];
  const uint16_t (*iris)[IRIS_MAP_WIDTH];
};

static const EyeDesign builtinDesigns[] = {
#if EYE_DEFAULT
    {"default", scleraDefault, upperDefault, lowerDefault, polarDefault, irisDefault},
#endif
#if EYE_NEWT
    {"newt", scleraNewt, upperNewt, lowerNewt, polarNewt, irisNewt},
#endif
#if EYE_ANIME
    {"anime", scleraAnime, upperAnime, lowerAnime, polarAnime, irisAnime},
#endif
#if EYE_BIGBLUE
    {"bigblue", scleraBigBlue, upperBigBlue, lowerBigBlue, polarBigBlue, irisBigBlue},
#endif
#if EYE_BLUEFLAME1
    {"blueflame1", scleraBlueFlame1, upperBlueFlame1, lowerBlueFlame1, polarBlueFlame1, irisBlueFlame1},
#endif
#if EYE_BLUEFLAME2
    {"blueflame2", scleraBlueFlame2, upperBlueFlame2, lowerBlueFlame2, polarBlueFlame2, irisBlueFlame2},
#endif
#if EYE_BROWN
    {"brown", scleraBrown, upperBrown, lowerBrown, polarBrown, irisBrown},
#endif
#if EYE_CAT
    {"cat", scleraCat, upperCat, lowerCat, polarCat, irisCat},
#endif
#if EYE_DEMON
    {"demon", scleraDemon, upperDemon, lowerDemon, polarDemon, irisDemon},
#endif
#if EYE_DOE
    {"doe", scleraDoe, upperDoe, lowerDoe, polarDoe, irisDoe},
#endif
#if EYE_DOOMRED
    {"doomred", scleraDoomRed, upperDoomRed, lowerDoomRed, polarDoomRed, irisDoomRed},
#endif
#if EYE_DOOMSPIRAL
    {"doomspiral", scleraDoomSpiral, upperDoomSpiral, lowerDoomSpiral, polarDoomSpiral, irisDoomSpiral},
#endif
#if EYE_DRAGON
    {"dragon", scleraDragon, upperDragon, lowerDragon, polarDragon, irisDragon},
#endif
#if EYE_FIREBOX
    {"firebox", scleraFirebox, upperFirebox, lowerFirebox, polarFirebox, irisFirebox},
#endif
#if EYE_FISH
    {"fish", scleraFish, upperFish, lowerFish, polarFish, irisFish},
#endif
#if EYE_FIZZGIG
    {"fizzgig", scleraFizzgig, upperFizzgig, lowerFizzgig, polarFizzgig, irisFizzgig},
#endif
#if EYE_FLAME
    {"flame", scleraFlame, upperFlame, lowerFlame, polarFlame, irisFlame},
#endif
#if EYE_HAZEL
    {"hazel", scleraHazel, upperHazel, lowerHazel, polarHazel, irisHazel},
#endif
#if EYE_HYPNORED
    {"hypnored", scleraHypnoRed, upperHypnoRed, lowerHypnoRed, polarHypnoRed, irisHypnoRed},
#endif
#if EYE_LEOPARD
    {"leopard", scleraLeopard, upperLeopard, lowerLeopard, polarLeopard, irisLeopard},
#endif
#if EYE_NEWT2
    {"newt2", scleraNewt2, upperNewt2, lowerNewt2, polarNewt2, irisNewt2},
#endif
#if EYE_SKULL
    {"skull", scleraSkull, upperSkull, lowerSkull, polarSkull, irisSkull},
#endif
#if EYE_SNAKEGREEN
    {"snakegreen", scleraSnakeGreen, upperSnakeGreen, lowerSnakeGreen, polarSnakeGreen, irisSnakeGreen},
#endif
#if EYE_SPIKES
    {"spikes", scleraSpikes, upperSpikes, lowerSpikes, polarSpikes, irisSpikes},
#endif
#if EYE_TOONSTRIPE
    {"toonstripe", scleraToonstripe, upperToonstripe, lowerToonstripe, polarToonstripe, irisToonstripe},
#endif
};

#define NUM_BUILTIN_DESIGNS (sizeof(builtinDesigns) / sizeof(builtinDesigns[0]))

// The design in the eye slot, loaded from a file rather than compiled in --
// see eyestore.h.  Always listed after the built-ins, at this index, so
// loading or removing it never renumbers them.
#define LOADED_DESIGN_INDEX NUM_BUILTIN_DESIGNS
static EyeDesign loadedDesign;
static bool loadedPresent = false;

// The file format fixes the table sizes; the renderer takes them from the
// headers.  A disagreement would have every loaded design read with the
// wrong row width, so it is made a build failure instead.
static_assert(SCLERA_WIDTH * SCLERA_HEIGHT * 2 == EYE_FILE_SCLERA_BYTES,
              "eye file sclera size");
static_assert(IRIS_MAP_WIDTH * IRIS_MAP_HEIGHT * 2 == EYE_FILE_IRIS_BYTES,
              "eye file iris size");
static_assert(SCREEN_WIDTH * SCREEN_HEIGHT == EYE_FILE_UPPER_BYTES &&
                  SCREEN_WIDTH * SCREEN_HEIGHT == EYE_FILE_LOWER_BYTES,
              "eye file eyelid size");
static_assert(IRIS_WIDTH * IRIS_HEIGHT * 2 == EYE_FILE_POLAR_BYTES,
              "eye file polar size");

static uint8_t designCount(void) {
  return NUM_BUILTIN_DESIGNS + (loadedPresent ? 1 : 0);
}

// Callers bound the index by designCount() first.
static const EyeDesign &designAt(uint8_t i) {
  return i < NUM_BUILTIN_DESIGNS ? builtinDesigns[i] : loadedDesign;
}

// Lists whatever the slot holds.  At boot, and after an upload succeeds.
static void adoptLoadedDesign(void) {
  EyeArt a;
  loadedPresent = eyeStoreArt(a);
  if (!loadedPresent)
    return;
  loadedDesign.name = eyeStoreName();
  loadedDesign.sclera = (const uint16_t(*)[SCLERA_WIDTH])a.sclera;
  loadedDesign.upper = (const uint8_t(*)[SCREEN_WIDTH])a.upper;
  loadedDesign.lower = (const uint8_t(*)[SCREEN_WIDTH])a.lower;
  loadedDesign.polar = (const uint16_t(*)[IRIS_WIDTH])a.polar;
  loadedDesign.iris = (const uint16_t(*)[IRIS_MAP_WIDTH])a.iris;
}

static uint8_t currentDesign = 0;

// Whether the eye has a pupil at all.  Off gives a full iris disc, which
// suits a clock face but is not tied to it.
static bool pupilOn = true;

// Panel assignment.  Swapping the chip-select pins moves everything that
// belongs to an eye -- its mirrored eyelids and its splash label -- to the
// other physical panel, which is what makes this a real fix for a miswire
// rather than a cosmetic one.
static bool eyesSwapped = false;
static bool swapPending = false;

// The CPU speed setting in MHz, 160 or 240: what the CPU is set to at the
// next boot.  The build's board_build.f_cpu is the default; a stored setting
// takes over when the settings load, which is before WiFi starts.  It is not
// switched live, because 160 and 240 come from different PLL frequencies:
// re-locking the PLL with the radio up cost 8.5 s of network every time it
// was tried.  240 draws faster, and draws more current -- docs/FRAME_RATE.md.
static uint8_t cpuSetting = F_CPU / 1000000;

static bool cpuValid(long mhz) { return mhz == 160 || mhz == 240; }

// A restart asked for over the console or the API.  Answered first and done
// from the render loop a moment later, so the caller gets its reply rather
// than a dropped connection it cannot tell from a crash.  A software restart,
// so the warnings list says nothing about it afterwards.
#define RESTART_DELAY_MS 1000
static bool restartPending = false;
static uint32_t restartAskedMs = 0;

// Which panels were mounted upside down.  Indexed by chip-select position --
// 0 for SELECT_L_PIN, 1 for SELECT_R_PIN -- and NOT by eye, because it is
// the panel that is the wrong way up, and it stays that way whichever eye
// is drawn on it.  A later `swap` moves the eyes and leaves these where
// they are, which is the only arrangement in which the two settings do
// not fight.  The rotation itself is done in the panel controller, see
// applyFlips(); nothing in the frame path knows about it.
static bool panelFlip[2] = {false, false};
static bool flipPending = false;

#if CLOCK

static bool clockOn = false;
static bool clockSeconds = true;
static uint16_t clockRate = 1;              // 1 = real time
static uint32_t clockBaseSec = 10 * 3600UL + 10 * 60UL; // 10:10, watch-ad time
static uint32_t clockBaseMs = 0;
static uint16_t clockHourAng, clockMinAng, clockSecAng;

// [0] hour, [1] minute, [2] second.  The 24-bit copies are kept only so
// `clock` can report what was asked for rather than the lossy 565 value.
static uint32_t clockRGB[3] = {CLOCK_HOUR_COLOR, CLOCK_MIN_COLOR,
                              CLOCK_SEC_COLOR};
static uint16_t clockPix[3];

// RRGGBB to RGB565: keep the top 5, 6 and 5 bits and pack them.
static inline uint16_t rgb24to565(uint32_t v) {
  return (uint16_t)(((v >> 8) & 0xF800) | ((v >> 5) & 0x07E0) |
                    ((v >> 3) & 0x001F));
}

// Keeps both representations: the 565 one is what gets drawn, the 24-bit
// one only so `clock` can echo back what was actually asked for.
static void clockSetColor(uint8_t which, uint32_t rgb) {
  clockRGB[which] = rgb & 0xFFFFFF;
  clockPix[which] = rgb24to565(clockRGB[which]);
}

// Rebases the free-running origin.  Everything else derives the current
// time from this pair, so setting the clock is just moving the origin.
static void clockSet(uint32_t secOfDay) {
  clockBaseSec = secOfDay % 86400UL;
  clockBaseMs = millis();
}

// Unit direction of each hand, 8.8 fixed point.  Recomputed once per frame
// rather than per pixel -- six trig calls a frame is nothing.
static int16_t clockDirX[3], clockDirY[3];

// The polar table's angle convention: a = (atan2(dy, dx) + PI) / 2PI * 512,
// which puts 12 o'clock at 128 and runs clockwise.
static void clockDirs(void) {
  const uint16_t ang[3] = {clockHourAng, clockMinAng, clockSecAng};
  for (uint8_t i = 0; i < 3; i++) {
    float th = (float)ang[i] * (2.0f * 3.14159265f / 512.0f) - 3.14159265f;
    clockDirX[i] = (int16_t)(cosf(th) * 256.0f);
    clockDirY[i] = (int16_t)(sinf(th) * 256.0f);
  }
}

// Recomputes the three hand angles and their direction vectors.  Called
// once per frame while the clock is on, never per pixel.
static uint32_t clockNow(void); // defined just below

static void clockUpdate(void) {
  uint32_t t = clockNow();
  uint32_t sec = t % 60, min = (t / 60) % 60, hr = (t / 3600) % 12;
  clockSecAng = (uint16_t)((CLOCK_NOON + sec * 512UL / 60UL) % 512UL);
  clockMinAng =
      (uint16_t)((CLOCK_NOON + (min * 60UL + sec) * 512UL / 3600UL) % 512UL);
  clockHourAng = (uint16_t)(
      (CLOCK_NOON + (hr * 3600UL + min * 60UL + sec) * 512UL / 43200UL) % 512UL);
  clockDirs();
}

// Seconds since midnight, derived rather than stored, so it stays correct
// however long the board has been up.
static uint32_t clockNow(void) {
  // Real time wins as soon as any source has supplied one -- NTP, or the RTC
  // at boot.  `clock rate` and `clock set` drive the free-running fallback
  // below, which is what runs until then, so they stop having an effect once
  // the clock is real.
  uint32_t secOfDay;
  if (timeIsExternal() && timeLocalSecOfDay(secOfDay))
    return secOfDay;

  uint32_t elapsed = ((millis() - clockBaseMs) / 1000UL) * clockRate;
  return (clockBaseSec + elapsed) % 86400UL;
}

#endif // CLOCK


// SETTINGS ----------------------------------------------------------------
// Stored in NVS, which already has a partition, so nothing else is needed.
//
// The eye design is saved by NAME rather than index: indices shift whenever
// the set of EYE_* switches changes, so a saved index could silently select a
// different design after a rebuild.  A name that is no longer built in falls
// back to the first design and says so.

static Preferences prefs;
static bool settingsDirty = false;

#define PREFS_NAMESPACE "creeper"
#define PREFS_KEY_EYE "eye"
#define PREFS_KEY_SWAP "swap"
#define PREFS_KEY_FLIP "flip" // bit 0: SELECT_L_PIN's panel, bit 1: SELECT_R_PIN's
#define PREFS_KEY_PUPIL "pupil"
#define PREFS_KEY_TZ "tz"
#define PREFS_KEY_NTP "ntp"
#define PREFS_KEY_CLOCK_ON "clkOn"
#define PREFS_KEY_CLOCK_SECONDS "clkSec"
#define PREFS_KEY_CLOCK_RATE "clkRate"
#define PREFS_KEY_CLOCK_HOUR_COLOR "clkC0"
#define PREFS_KEY_CLOCK_MINUTE_COLOR "clkC1"
#define PREFS_KEY_CLOCK_SECOND_COLOR "clkC2"
#define PREFS_KEY_SLEEP_ON "slpOn"
#define PREFS_KEY_SLEEP_START "slpStart"
#define PREFS_KEY_SLEEP_STOP "slpStop"
#define PREFS_KEY_SLEEP_LEVEL "slpLevel"
#define PREFS_KEY_DIM "dim"
#define PREFS_KEY_DIM_GAMMA "dimGamma" // tenths: 22 is gamma 2.2
#define PREFS_KEY_DIM_TRIM_L "dimTrim0" // SELECT_L_PIN's panel, -50..50
#define PREFS_KEY_DIM_TRIM_R "dimTrim1" // SELECT_R_PIN's
#define PREFS_KEY_CPU "cpuMHz" // written when it changes, not by save

// The clock's display preferences are saved; the time itself is not.
// Restoring a time from whenever the power went off would be wrong by
// exactly that interval, and NTP or the RTC supplies the real one, which
// makes a stored one pointless as well as misleading.

static void saveSettings(void) {
  prefs.begin(PREFS_NAMESPACE, false);
  prefs.putString(PREFS_KEY_EYE, designAt(currentDesign).name);
  prefs.putBool(PREFS_KEY_SWAP, eyesSwapped);
  prefs.putUChar(PREFS_KEY_FLIP,
                 (uint8_t)((panelFlip[0] ? 1 : 0) | (panelFlip[1] ? 2 : 0)));
  prefs.putBool(PREFS_KEY_PUPIL, pupilOn);
  prefs.putString(PREFS_KEY_TZ, tzString);
#if NETWORK
  prefs.putBool(PREFS_KEY_NTP, netNtpEnabled());
#endif
#if CLOCK
  prefs.putBool(PREFS_KEY_CLOCK_ON, clockOn);
  prefs.putBool(PREFS_KEY_CLOCK_SECONDS, clockSeconds);
  prefs.putUShort(PREFS_KEY_CLOCK_RATE, clockRate);
  prefs.putULong(PREFS_KEY_CLOCK_HOUR_COLOR, clockRGB[0]);
  prefs.putULong(PREFS_KEY_CLOCK_MINUTE_COLOR, clockRGB[1]);
  prefs.putULong(PREFS_KEY_CLOCK_SECOND_COLOR, clockRGB[2]);
  // Not the time -- see the note by the keys.
#endif
#if SLEEP
  prefs.putBool(PREFS_KEY_SLEEP_ON, sleepEnabled());
  prefs.putUShort(PREFS_KEY_SLEEP_START, sleepStart());
  prefs.putUShort(PREFS_KEY_SLEEP_STOP, sleepStop());
  prefs.putUChar(PREFS_KEY_SLEEP_LEVEL, sleepLevel());
#endif
  prefs.putUChar(PREFS_KEY_DIM, dimmerPercent());
  prefs.putUChar(PREFS_KEY_DIM_GAMMA, dimmerGammaX10());
  prefs.putChar(PREFS_KEY_DIM_TRIM_L, dimmerTrim(0));
  prefs.putChar(PREFS_KEY_DIM_TRIM_R, dimmerTrim(1));
  prefs.end();
  settingsDirty = false;
}

// Wipes the whole namespace, so the build defaults apply at the next boot.
static void forgetSettings(void) {
  prefs.begin(PREFS_NAMESPACE, false);
  prefs.clear();
  prefs.end();
  settingsDirty = false;
  cpuSetting = F_CPU / 1000000; // the build's speed again, from the next boot
}

#if RAM_TABLES
// The two tables drawEye() reads out of order -- the polar map and the iris
// -- copied into RAM whenever the design changes, so a flash cache miss
// cannot cost them; see RAM_TABLES.  Allocated at the first design change and
// kept.  Both or neither: if either allocation fails, both are freed and the
// renderer reads flash, as it always did, until the next design change tries
// again.  The first failure is a warning, since it costs frames; the retries
// are not, or every design change would add another.
static uint16_t *ramPolar = NULL, *ramIris = NULL;
static bool ramTablesWarned = false;
#endif

// Repoints the five artwork pointers at another design.  drawEye() reads them
// per pixel, so this must run between frames or it tears one.  Reached
// through pendingEyeDesign, never directly from an operation -- except
// dropLoadedDesign(), which explains why it cannot wait.  Out-of-range falls
// back to the first design.
static void applyDesign(uint8_t idx) {
  if (idx >= designCount())
    idx = 0;
  const EyeDesign *d = &designAt(idx);
  sclera = d->sclera;
  upper = d->upper;
  lower = d->lower;
  polar = d->polar;
  iris = d->iris;
#if RAM_TABLES
  if (!ramPolar) {
    ramPolar = (uint16_t *)malloc(sizeof(uint16_t) * IRIS_WIDTH * IRIS_HEIGHT);
    ramIris = (uint16_t *)malloc(sizeof(uint16_t) * IRIS_MAP_WIDTH * IRIS_MAP_HEIGHT);
    if (!ramPolar || !ramIris) {
      free(ramPolar);
      free(ramIris);
      ramPolar = ramIris = NULL;
      if (!ramTablesWarned)
        healthNote("no memory for the eye tables in RAM; frames are slower");
      ramTablesWarned = true;
    }
  }
  if (ramPolar) {
    memcpy(ramPolar, d->polar, sizeof(uint16_t) * IRIS_WIDTH * IRIS_HEIGHT);
    memcpy(ramIris, d->iris, sizeof(uint16_t) * IRIS_MAP_WIDTH * IRIS_MAP_HEIGHT);
    polar = (const uint16_t(*)[IRIS_WIDTH])ramPolar;
    iris = (const uint16_t(*)[IRIS_MAP_WIDTH])ramIris;
  }
#endif
  currentDesign = idx;
#if CONTROLLABLE
  settingsDirty = true;
#endif
}

// DISPLAY HARDWARE CONFIG -------------------------------------------------

// Which panel is fitted.  Set from platformio.ini build_flags; the SSD1351
// colour path is the default so the RGB build is unaffected.
//   SSD1351 - Waveshare 1.5" RGB OLED, 65K colour, 16 bits/pixel
//   SSD1327 - Waveshare 1.5" OLED,     16 greys,   4 bits/pixel
#ifndef USE_SSD1327
#define USE_SSD1327 0
#endif

#if USE_SSD1327
#include "ssd1327.h"
using PanelDriver = SSD1327;
// Two panels on one bus; drop this if long jumpers make it unreliable.
#ifndef SSD1327_SPI_HZ
#define SSD1327_SPI_HZ 8000000
#endif
static SPISettings graySPI(SSD1327_SPI_HZ, MSBFIRST, SPI_MODE0);
#else
#include <Adafruit_SSD1351.h> // OLED display library -OR-

// Adafruit_SPITFT keeps its chip-select pin in a protected member with no
// setter, so a thin subclass exposes it.  That lets a miswired pair of
// panels be swapped in software rather than rewired -- see `swap`.
class SwappableSSD1351 : public Adafruit_SSD1351 {
public:
  using Adafruit_SSD1351::Adafruit_SSD1351;
  void setCS(int8_t pin) { _cs = pin; }
};

using PanelDriver = SwappableSSD1351;

// The colour panels' bus speed.  A colour frame is 32 KB, four times a
// greyscale one, so this is most of the colour frame rate: at the library's
// default of 8 MHz sending one eye took 33 ms of a 53 ms frame, and the
// frame rate was 19.  16 MHz gives 28-29.  20 MHz, the SSD1351's rated
// maximum, gave 30-31 but speckled one of frank-dev's two panels on the
// carrier board, so the default stays a step below it; both divide the
// ESP32's 80 MHz exactly.  Lower it if long jumpers speckle the image.
#ifndef SSD1351_SPI_HZ
#define SSD1351_SPI_HZ 16000000
#endif
#endif
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
void loop() {

  // Autonomous iris scaling -- invoke recursive function

  static uint16_t oldIris = (IRIS_MIN + IRIS_MAX) / 2;
  uint16_t newIris = random(IRIS_MIN, IRIS_MAX);

  walkIris(oldIris, newIris, micros(), 10000000L, IRIS_MAX - IRIS_MIN);
  oldIris = newIris;
}

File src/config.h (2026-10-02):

// Build-time configuration.
//
// Each switch is #ifndef-guarded, so platformio.ini can override any of them
// without this file being edited:
//
//   build_flags = -DNETWORK=0 -DCLOCK=0
//
// See the environments in platformio.ini for the combinations that ship.
//
// Everything in this file is overridable except the include guard, the names
// derived from other settings (CONTROLLABLE, OTA_AUTH, FIRMWARE_COMMIT and
// the DEBUG_* macros), the fixed limits DIM_GAMMA_MIN and DIM_GAMMA_MAX, and
// the two FAVICON_* values that FAVICON selects between.
//
// Not quite everything is here.  The switches this project inherited from
// upstream -- USE_SSD1327, SSD1327_SPI_HZ, SSD1351_SPI_HZ, STARTLE_WINDUP_MS,
// STARTLE_HOLD_MS, TRACKING, AUTOBLINK and IRIS_MIN/IRIS_MAX -- are still
// declared in main.cpp beside the rendering code they belong to.  They are
// overridable from build_flags just the same; USE_SSD1327 is set that way by
// the `gray` environment.

#ifndef CONFIG_H
#define CONFIG_H

// NETWORK -----------------------------------------------------------------
// Credentials live in include/secrets.h, which is gitignored -- copy
// include/secrets.h.example to get started.  Nothing secret is committed,
// and a clone without it still builds: the include is guarded, and an
// unconfigured board falls through to the setup portal.

#ifndef NETWORK
#define NETWORK 1
#endif

#ifndef WIFI_HOSTNAME
#define WIFI_HOSTNAME "frank"
#endif
#ifndef WIFI_AP_NAME
#define WIFI_AP_NAME "frank-setup"
#endif

// The legacy /cmd?c=... endpoint, which runs a console command over HTTP
// and answers in prose.  Handy from a shell, but the JSON API under
// /api/v1 is what programs should use.  Set to 0 to drop it.
#ifndef WEB_CMD_ENDPOINT
#define WEB_CMD_ENDPOINT 1
#endif

// The web server is served from the render loop, so a request is only
// taken once all of it has arrived -- see AuthWebServer::handleClient().
// The most a request's head may be, the most its body may be (the eye file,
// which is streamed, aside), and how long all of it has to arrive.  Head
// and body together must stay inside the TCP window, 5760 bytes, or a
// request that is allowed could never arrive in full.
#ifndef REQUEST_HEAD_MAX
#define REQUEST_HEAD_MAX 3072
#endif
#ifndef REQUEST_BODY_MAX
#define REQUEST_BODY_MAX 2048
#endif
#ifndef REQUEST_ARRIVE_MS
#define REQUEST_ARRIVE_MS 5000
#endif
#if REQUEST_HEAD_MAX + REQUEST_BODY_MAX > 5760
#error "REQUEST_HEAD_MAX + REQUEST_BODY_MAX must fit the TCP window (5760)"
#endif

// How long to wait on a known network before giving up and opening the
// portal, and how long the portal itself stays up before the eyes carry on
// regardless.  A prop with no network should still be a working prop.
#ifndef WIFI_CONNECT_MS
#define WIFI_CONNECT_MS 15000
#endif
// How long to wait between attempts once the board has given up at boot.
// Watching for a link is not enough on its own: the setup portal tears the
// association down when it times out, so nothing is trying any more and a
// network that comes back would never be noticed.
#ifndef WIFI_RETRY_MS
#define WIFI_RETRY_MS 30000
#endif

#ifndef WIFI_PORTAL_S
#define WIFI_PORTAL_S 60
#endif

// How long `net` leaves the address cards up before the eyes resume.
#ifndef NET_SHOW_MS
#define NET_SHOW_MS 12000
#endif

// 128 px at 6 px per character in the default font.
#ifndef NET_COLS
#define NET_COLS 21
#endif

// The time servers, in the order they are asked.
#ifndef NTP_SERVER_1
#define NTP_SERVER_1 "pool.ntp.org"
#endif
#ifndef NTP_SERVER_2
#define NTP_SERVER_2 "time.nist.gov"
#endif

// US Pacific by default.  A POSIX TZ string carries the DST *rules*, not
// just an offset -- "PST8PDT" names both standard and summer time, and
// "M3.2.0/2,M11.1.0/2" is the US changeover: second Sunday in March at
// 02:00, first Sunday in November at 02:00.  So DST is not a separate
// setting -- no offset plus a checkbox -- and nothing needs touching twice a
// year.
#ifndef TZ_DEFAULT
#define TZ_DEFAULT "PST8PDT,M3.2.0/2,M11.1.0/2"
#endif
#ifndef TZ_MAX
#define TZ_MAX 48
#endif

// Optional: a clone without it still builds, and an unconfigured board
// falls through to the setup portal.
#if defined(__has_include)
#if __has_include("secrets.h")
#include "secrets.h"
#endif
#endif

#ifndef WIFI_SSID
#define WIFI_SSID ""
#endif
#ifndef WIFI_PASS
#define WIFI_PASS ""
#endif

// DEBUG OUTPUT ------------------------------------------------------------
// Set DEBUG to 0 to compile out all serial diagnostics (no code, no strings,
// and Serial is never opened).  DEBUG_BAUD feeds Serial.begin() here and must
// be kept in sync with monitor_speed in platformio.ini.

#ifndef DEBUG
#define DEBUG 1
#endif
#ifndef DEBUG_BAUD
#define DEBUG_BAUD 115200
#endif
// On-board user LED of the DOIT ESP32 DevKit V1, silkscreened "D2".
// Not broken out to a header pin and unused by the eyes, so it is free.
#ifndef DEBUG_LED_PIN
#define DEBUG_LED_PIN 2
#endif
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

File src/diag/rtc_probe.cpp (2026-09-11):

// Bring up a DS3231 without any of the rest of the firmware in the way.
//
//   pio run -e rtc_probe -t upload -t monitor
//
// The same idea as ssd1327_probe.cpp: when a new part will not talk, the
// question is always "is it the wiring or is it my code", and the only way to
// answer it is to take the code out of the picture.  This scans the bus,
// reports every address that answers, and then reads the chip raw.
//
// What you should see, with a module wired per docs/WIRING_RTC.md:
//
//   scan: found 0x57  (AT24C32 EEPROM)
//   scan: found 0x68  (DS3231)
//   status 0x00  oscillator has run continuously
//   raw 00..06: 12 34 09 03 10 09 26
//   -> 2026-09-10 09:34:12 UTC   temp 24.75 C
//
// A bus with nothing on it reports no addresses at all: check 3V3, GND, and
// that SDA and SCL are not swapped.  Only 0x57 answering means the DS3231
// half of the board is not being powered or is faulty.

#include <Arduino.h>
#include <Wire.h>

#define SDA_PIN 21
#define SCL_PIN 22
#define DS3231 0x68

static uint8_t fromBcd(uint8_t v) { return (uint8_t)((v >> 4) * 10 + (v & 0x0F)); }

static bool readRegs(uint8_t reg, uint8_t *buf, uint8_t n) {
  Wire.beginTransmission(DS3231);
  Wire.write(reg);
  if (Wire.endTransmission() != 0)
    return false;
  if (Wire.requestFrom((int)DS3231, (int)n) != n)
    return false;
  for (uint8_t i = 0; i < n; i++)
    buf[i] = (uint8_t)Wire.read();
  return true;
}

void setup(void) {
  Serial.begin(115200);
  delay(400);
  Serial.println();
  Serial.printf("[rtc probe] SDA=%d SCL=%d\n", SDA_PIN, SCL_PIN);

  Wire.begin(SDA_PIN, SCL_PIN);
  Wire.setTimeOut(50);
}

void loop(void) {
  // A full scan every time, because the interesting failure is intermittent
  // wiring, and a single boot-time scan would miss it.
  uint8_t found = 0;
  for (uint8_t a = 1; a < 127; a++) {
    Wire.beginTransmission(a);
    if (Wire.endTransmission() == 0) {
      found++;
      const char *what = a == DS3231  ? "  (DS3231)"
                         : a == 0x57  ? "  (AT24C32 EEPROM)"
                                      : "";
      Serial.printf("scan: found 0x%02X%s\n", a, what);
    }
  }
  if (!found)
    Serial.println("scan: nothing on the bus -- check 3V3, GND, SDA and SCL");

  uint8_t st;
  if (readRegs(0x0F, &st, 1))
    Serial.printf("status 0x%02X  %s\n", st,
                  (st & 0x80) ? "OSCILLATOR HAS STOPPED -- time not valid"
                              : "oscillator has run continuously");

  uint8_t r[7];
  if (readRegs(0x00, r, sizeof(r))) {
    Serial.printf("raw 00..06:");
    for (uint8_t i = 0; i < sizeof(r); i++)
      Serial.printf(" %02X", r[i]);
    Serial.println();
    Serial.printf("-> 20%02u-%02u-%02u %02u:%02u:%02u UTC",
                  fromBcd(r[6]), fromBcd(r[5] & 0x1F), fromBcd(r[4] & 0x3F),
                  fromBcd(r[2] & 0x3F), fromBcd(r[1] & 0x7F),
                  fromBcd(r[0] & 0x7F));
    uint8_t t[2];
    if (readRegs(0x11, t, 2))
      Serial.printf("   temp %.2f C", (float)(int8_t)t[0] + (t[1] >> 6) * 0.25f);
    Serial.println();
  }

  Serial.println();
  delay(3000);
}

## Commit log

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2026-09-09 Support SSD1327 grayscale panels; fix shared-reset and chip-select bugs
    Target a generic ESP32 dev board and add an optional grayscale display
    path, plus two genuine bugs found while bringing the hardware up.
    Build:
    - board is now esp32dev (generic WROOM-32) rather than featheresp32.
    - SPI.begin(5, 19, 18) is now explicit. The pin assignments in the README
    only worked because they matched the Feather variant's default SPI
    pins; on a generic board those defaults are MOSI=23/SCK=18, so the
    panels would have received no clock or data, with no build error.
    - monitor_speed lowered to 115200 to match the ROM bootloader, so boot
    messages and sketch output land in one readable stream.
    Fixe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
    [main.cpp, ssd1327.h]
2026-09-10 Fix eyelid edge artifact at the mirrored eye's edge
    drawEye() mirrors the left eye's eyelids by reversing the X coordinate of
    the eyelid lookup:
    int effectiveX = e == 1 ? screenX : SCREEN_WIDTH - screenX;
    screenX runs 0..127 and the eyelid maps are [128][128], so for e == 0 this
    produced 128..1 -- one past the end of each row at screenX == 0, and never
    index 0 at all. Since C arrays are contiguous, upper[y][128] reads
    upper[y+1][0], and on the final row it reads past the array entirely. The
    corrupted column only showed where the eyelid boundary crossed it, which is
    why it appeared as a small teardrop at a corner rather than a full stripe.
    Use SCREEN_WIDTH - 1 - screenX so the range is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
    [main.cpp]
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2026-09-10 Label splash from both perspectives, and fix which eye is which
    The splash had the sides backwards. Verified on the bench: the panel on
    SELECT_L_PIN (D15) sits on the viewer's left, which is FRANK'S RIGHT eye.
    The upstream L/R pin names are viewer-relative; anatomical left and right
    are always given from the subject's own side, so eye[0] is Frank's right.
    Each panel now names itself both ways -- "FRANK'S RIGHT" over "YOUR LEFT",
    separated by a rule -- because every previous attempt to write this down,
    in the sketch and in the README, left the perspective unstated. The pin
    defines now carry the mapping in a comment for the same reason.
    C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
    [main.cpp]
2026-09-10 Add a serial command console and BOOT-button eye toggle
    Replaces the vestigial UART command plumbing with something usable. What
    survived of the original was one hook -- serEyeCtrl, the flag that makes
    the motion code hold a commanded gaze instead of drifting. The parser, the
    command semantics and SerialIn.begin() were all gone, and the protocol it
    implied (a 9-byte addressed binary format for a master controller driving
    several eye pairs over a second UART on GPIO13) needs a second device wired
    to a pin that is unreachable once the head is assembled.
    The USB cable that powers the board is already a serial line, so the
    console lives there instead. No extra wiring, and it works in
    `pio devic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
    [main.cpp]
2026-09-10 Add pupil dilation control to the console
    dilate <0-100> pupil width, 100 = fully dilated
    dilate auto return to autonomous dilation
    loop() walks the iris scale randomly between IRIS_MIN and IRIS_MAX via
    split(); while a dilation is commanded, frame() ignores that walk. Nothing
    about the autonomous path changes, so releasing control resumes it mid-walk
    with no discontinuity.
    The underlying scale runs backwards -- it divides into the iris map, so
    IRIS_MIN is the widest pupil and IRIS_MAX the narrowest. The command takes
    a plain percentage and inverts it, so 100 reads as "fully dilated" rather
    than requiring callers to know the internals.
    Commanded changes ease in over roughly a f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
    [main.cpp]
2026-09-10 Add a startle effect, and fix the dilation easing stall
    startle constrict slowly, then snap wide with a blink
    Runs as a state machine polled once per frame rather than with delay(),
    which would freeze rendering for the ~2.6 s the effect lasts. Frame rate
    holds at ~44 fps throughout.
    Windup constricts to a pinpoint over 1.4 s with the easing rate slowed to a
    sixth of normal, then the pupil is snapped fully open by writing the eased
    value directly rather than letting it glide, with a blink on the same
    frame. After 1.2 s held wide, whatever was in effect beforehand is restored
    -- autonomous walk or a previously commanded width, whichever it took over
    from. An explicit dilate command cance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
    [main.cpp]
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2026-09-10 Make the set of eye designs configurable at build time
    Both designs were compiled in unconditionally and switched with a bool.
    Each one costs ~165 KB of flash, which the default 1.25 MB app partition
    cannot absorb indefinitely, so which designs are present is now a build
    choice and the runtime switch works off a registry rather than an if/else.
    include/eyes_config.h holds one switch per design, each #ifndef-guarded so
    platformio.ini can override without editing the file:
    build_flags = -DEYE_NEWT=0
    Dropping the newt eye takes the image from 615 KB to 457 KB. Enabling none
    fails with an #error rather than a confusing cascade -- the eye headers are
    also where the SCLERA_*, IRIS_* and SCR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
    [main.cpp]
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2026-09-10 Swap the panels in software, and remember settings across reboots
    SWAP
    `swap` exchanges the chip-select pins so a miswired pair can be corrected
    without opening the head.
    This exchanges the pins themselves rather than relabelling the sides, so
    everything belonging to an eye moves with it -- its mirrored eyelids and its
    splash label -- and anything per-eye added later will follow automatically.
    Adafruit_SPITFT keeps its chip select in a protected member with no setter,
    so the colour path gets a thin subclass that exposes it; SSD1327 gets the
    same setter directly. The swap is applied from frame(), between renders,
    because one landing mid-transaction would leave a chip select asserted on
    the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
    [main.cpp, ssd1327.h]
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2026-09-10 Clock: thicker hands, runtime colours, and a full-dial mode
    Hands are twice as wide and default to black.
    Black alone did not work, though. The pupil is black and fills most of the
    iris disc, so hands drawn across it were swallowed and only stubs showed on
    the thin remaining ring -- unreadable on both a light iris and a dark one.
    So the clock now opens the pupil right out while it is showing. The iris is
    drawn where iScale * distance / 128 < 64, and distance peaks at 127 at the
    centre, so any scale at or below 64 keeps every pixel in the iris and the
    pupil vanishes. The whole iris becomes a dial and black hands read cleanly
    against it. `clock pupil on` restores the pupil for anyone who pre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
    [main.cpp]
2026-09-10 Clock: draw hands as real lines instead of polar wedges
    The hands came out as pie wedges, and not because anything warped them --
    they were defined that way. Testing each pixel for "within this length and
    within this many degrees of the hand" describes a wedge by construction:
    zero width at the centre, widening to the tip. Making them thicker just
    widened the wedge.
    They are now drawn after the eye is rendered, straight into the finished
    frame, as line segments of constant pixel width. Lengths and widths are in
    pixels rather than angle units.
    This is also considerably cheaper. The old version tested all 16384 pixels
    of every frame against three hands; this touches only the few hundred
    pixe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
    [main.cpp]
2026-09-10 Clock: rasterise hands as filled quads; make pupil its own command
    HANDS
    Thick hands were drawn as a set of parallel offset lines, one per unit of
    half-width. Each was rounded independently, so neighbouring offsets landed
    on the same pixel at most angles -- gaps along one edge, doubled pixels
    along the other. Two more faults compounded it: the shift truncated instead
    of rounding, biasing every point by up to a pixel, and stepping one
    Euclidean pixel along the hand let the rounded position jump diagonally,
    leaving the single-pixel second hand only 8-connected.
    Each hand is now rasterised as a filled quad: a tight bounding box, then
    per pixel the projection along the hand tested against its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
    [main.cpp]
2026-09-10 Persist the pupil and clock settings too
    save/load covered only the eye design and the swap flag. Everything added
    since was lost on a power cycle, which defeats the point for a sealed prop.
    Now stored as well: the pupil flag, whether the clock is running, the second
    hand, the rate, all three hand colours, and the time.
    Saving the time is a judgement call worth stating. With no real time source
    the clock restarts wherever it was saved, so it is wrong by however long the
    power was off. That is still better than always reverting to the built-in
    default, but it is a starting point rather than a clock, and the comment in
    saveSettings() says so.
    Hand angles are recomputed at the end of loadSet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
    [main.cpp]
2026-09-10 Do not persist the clock
    Without a real time source a restored clock comes back wrong by however
    long the power was off, and a running clock showing the wrong time reads as
    broken rather than as unset. Better to start unset and let it be set
    deliberately, until there is something to sync against.
    Everything clock-related is dropped from the store: running state, second
    hand, rate, hand colours and the time. Changing any of them no longer marks
    settings dirty, since there is nothing to save.
    The pupil flag stays persisted -- it is a plain display preference with no
    dependence on wall-clock time -- alongside the eye design and the swap flag.
    Verified: set clock and pupil, save, power cycle.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
    [main.cpp]
2026-09-10 Persist the clock's display preferences, but not the time
    Restores what the previous commit removed too broadly. Running state, second
    hand, rate and all three hand colours are display preferences and belong in
    the store; the time does not.
    Restoring a time saved at power-off would be wrong by exactly the interval
    the device was off, and the plan is to take the time from NTP, which makes a
    stored one pointless as well as misleading. The clock starts at its built-in
    default and waits to be set.
    `clock set` therefore does not mark settings dirty, since it changes only
    the time. Every other clock command does.
    Verified: set rate, seconds, colour, time and pupil, save, power cycle.
    Everything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
    [main.cpp]
2026-09-10 Bring the documentation up to date with the clock and pupil work
    README was missing both new commands and described a smaller set of saved
    settings than the firmware actually stores.
    - Adds `pupil` and the five `clock` sub-commands to the command table.
    - New sections for the pupil and the clock face, including why removing the
    pupil stops `dilate` from doing anything, and why the hands being drawn
    after the eye means they work with or without a pupil.
    - Rewrites the persistence section around a table of what is and is not
    saved. Gaze and dilation are transient by design; the clock's time is
    excluded because a time restored from power-off is wrong by exactly the
    interval the devic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
    [main.cpp]
2026-09-10 Comment pass over the code added by this fork
    Audited rather than skimmed: parsed every function definition and checked
    whether anything explains it. Found 17 in main.cpp, 7 in tools/gen_eyes.py
    and 3 in the SSD1327 probe with nothing above them.
    Comments say what is not already obvious from the name, rather than
    restating it. The ones worth having:
    - setup() now lists its ordering constraints, none of which are visible from
    reading it: an eye design must be selected before anything renders because
    the artwork pointers start unset; chip selects are parked before the shared
    reset is pulsed; that reset is pulsed exactly once because doing it per
    panel wipes the first; and settings lo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
    [main.cpp, ssd1327_probe.cpp]
2026-09-10 Add WiFi bring-up with a setup portal fallback
    Connects on boot, and gets out of the way when it cannot.
    CREDENTIALS
    Not via secrets.ini and build_flags, which is what I set out to do and what
    would be the idiomatic PlatformIO route. build_flags are processed by SCons,
    which uses '$' as its own substitution character: a password containing '$'
    is silently truncated there. Not an error -- just a shorter string and a
    board that will not associate. Doubling the '$' does not help either; the
    value still arrived cut off at the first one, verified by searching the
    compiled image.
    So credentials live in include/secrets.h instead, gitignored, with
    secrets.h.example committed alongside. The prepro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
    [main.cpp]
2026-09-10 Add mDNS and a network info display
    The board answers to frank.local, and `net` reports its addresses both over
    serial and on the panels.
    The panels split the information rather than sharing it: a link-local IPv6
    address runs to 39 characters and a 128 px panel holds 21, so it will not
    fit alongside anything else. Frank's right gets the MAC, IPv4 and signal
    strength; his left gets IPv6, wrapped across lines rather than truncated,
    plus the mDNS name. Using the two displays for two halves of the same
    information is the tidiest answer available.
    Address cards are non-blocking: frame() skips the eye render until the
    deadline passes, so the console stays responsive and a second `net`
    refreshes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
    [main.cpp]
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2026-09-10 Make every feature switch a build option, and add no-network builds
    The guards were already right -- flipping NETWORK to 0 compiled cleanly --
    but the switch could not actually be set from the build. Only USE_SSD1327
    was #ifndef-guarded; NETWORK, CLOCK, COMMANDS, DEBUG and STARTUP_SPLASH were
    hard-coded, so a -D from platformio.ini was silently ignored and the file's
    own value won. Anyone wanting a build without networking had to edit source.
    All five are now overridable, and two environments use it:
    pio run -e gray_local ; greyscale, nothing on the network
    pio run -e esp32dev_local ; colour, likewise
    No WiFi, NTP, web server or OTA -- for anyone who would rather not add
    another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
    [main.cpp]
2026-09-10 Split the networking out of main.cpp
    main.cpp was 2285 lines. The networking is now four files, and anyone
    building without it can ignore two of them entirely.
    src/config.h every build switch and tunable, in one place
    src/display.h the text-rendering entry points other modules need
    src/console.h the command dispatcher's public surface
    src/net.h/.cpp WiFi, the portal, mDNS, NTP, the address cards
    src/web.cpp the web interface and OTA
    main.cpp drops to 1712 lines.
    WHAT WAS NOT SPLIT, AND WHY
    The console, settings and the eye rendering stay in main.cpp. Extracting
    them would mean publishing most of the program's state as extern -- gaze,
    dilation, blink, swap, pupil, th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
    [config.h, main.cpp]
2026-09-10 Add a device operations layer, and rewire the console onto it
    Phase one of making the web interface a real API. No visible change: the
    console behaves exactly as before, verified command by command.
    The problem this solves is that the console *was* the interface. The web
    server worked by synthesising command strings and handing them to
    handleCommand(), so every HTTP call round-tripped through a text parser, and
    the console's human-readable output was load-bearing for machines -- reword
    "ok eye=1 newt" and you break every client.
    state.h now declares what the device can be asked to do, as functions that
    return success rather than printing. The console parses words and calls
    them; the JSON A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
    [main.cpp]
2026-09-10 Add a versioned JSON REST API
    /api/v1, JSON in and out, with real verbs and real status codes.
    GET /api/v1/state everything, for a UI to poll
    GET /api/v1/eyes the designs in this build
    GET PUT /api/v1/eye {"name":"newt"} | {"index":1} | {"next":true}
    GET PUT /api/v1/gaze {"x":200,"y":800} | {"mode":"auto"}
    GET PUT /api/v1/dilate {"percent":75} | {"mode":"auto"}
    GET PUT /api/v1/pupil {"on":false}
    GET PUT /api/v1/swap {"on":true}
    GET PUT /api/v1/clock partial: any subset of fields is applied
    GET PUT /api/v1/tz {"tz":"pacific"} or a POSIX string
    GET /api/v1/net addresses, signal, time
    POST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
    [config.h]
2026-09-10 Let the address cards be dismissed, and untangle COMMANDS from NETWORK
    `net` painted the addresses onto both panels for twelve seconds with no way
    back, which is a long time to stare at a MAC address. The overlay is now a
    resource rather than a one-shot -- `GET|PUT /api/v1/netinfo`, `net off` over
    serial -- and /state reports whether it is up, so a client can offer the way
    back too. `action: netinfo` stays as a synonym for raising it.
    The rest is a switch-design fix that the API exposed. COMMANDS was doing two
    jobs: gating the serial console, and gating everything that can change the
    device at runtime. With a second interface onto that same machinery, the two
    have to come apart -- COMMA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
    [config.h, main.cpp]
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2026-09-10 Fill in the gaps in the control page, and fix WiFi credential storage
    Seven things, most of them the page not being finished:
    - Hand colours had no control at all. Three swatches now, and /state reports
    the panel type so the page can say that a colour on a greyscale panel is
    going to arrive as a brightness.
    - The clock's time could not be typed in. It can now, with the card saying
    plainly that NTP overrides it and that it is not saved either way.
    - Ten timezones was not "worldwide". Sixty-one now, IANA city names grouped
    by region, with the old regional names kept as aliases and a field for a
    raw POSIX string for anywhere still not covered.
    - Swap panels was filed under Pupil. It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
    [main.cpp]
2026-09-10 Fix the page stalling, and stamp builds with a version
    The control page would stop responding after a while. Not a leak -- heap is
    flat over a soak -- but two things compounding:
    The board had WiFi modem sleep on, which is the Arduino default. It parks
    the radio between beacons, and one small GET measured at a 1.7 s median with
    a tenth of them past eight seconds. With sleep off the same request takes
    65 ms and none time out. Roughly 30 mA, which is nothing for a prop on a USB
    lead.
    And the page polled on a setInterval, which fires whether or not the last
    request has come back. The board serves one client at a time from inside its
    render loop, so a slow reply left a second request outs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
    [config.h, main.cpp]
2026-09-10 Compile IPv6 out entirely
    The address was still on the control page, on the address cards and in
    /api/v1/net, and it cannot be connected to: nothing listens on it, and it is
    link-local besides. An address on screen that does not work is one more
    thing to be puzzled by, so none of it is compiled in now -- bringing the
    address up, reporting it, and printing it are all behind the switch together.
    The switch is called IPV6 rather than IPV6_SERVER for that reason; it stopped
    being only about whether a socket listens. Setting it to 1 brings the lot
    back at once, and both states build.
    Frank's left address card was carrying the IPv6 address and little else, so
    it now shows the name to type and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
    [config.h]
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2026-09-10 Audit pass: fix stale comments, and annotate the Python
    Nothing secret: no password or SSID in any of 203 tracked files, or in any
    commit on any branch, and this board's MAC and LAN addresses are not
    committed either. include/secrets.h is untracked and ignored, the example
    template is not.
    Documentation was complete -- all 17 console commands and all 15 API routes
    are in the README, and every command is in the built-in `help` -- but three
    things had gone stale:
    - config.h claimed "every switch and tunable in one place", and the README
    said all of them live there. Seven do not: USE_SSD1327, SSD1327_SPI_HZ,
    the two STARTLE_ timings, TRACKING, AUTOBLINK and IRIS_MIN/MAX are still
    decl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
    [config.h]
2026-09-11 Add an optional battery-backed clock
    A DS3231 on four wires, so the head knows what time it is after a power cut
    and with no network ever configured -- set it once and it is kept, to about a
    minute a year. Off by default; a build without it is byte-for-byte what it
    was.
    The chip holds UTC, not local time, which is the whole reason this needed
    more than a driver. Storing local would leave a head unplugged in February
    and switched on in July an hour out, with no network to correct it. So the
    timezone and the system clock have moved out of net.cpp into timekeeping.cpp,
    which is compiled into every build: net.cpp and rtc.cpp are now two sources
    feeding one clock, neither required. `tz` work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
    [config.h, main.cpp, rtc.cpp]
2026-09-11 Show both time sources on the page, and let NTP be switched off
    The page reported "synced" or "not synced" and nothing else, which said
    nothing about whether a time server was reachable, when it last answered, or
    whether an RTC was fitted at all. It now shows a row per source -- the one
    in charge, then NTP, then the RTC -- each with a state, a colour, and the
    detail that justifies it: which server and how often, or that the module is
    missing and the wiring wants checking.
    /api/v1/state gains a `time` block carrying all of it, so the page reads it
    on the poll it already makes rather than opening a second connection against
    a server that handles one client at a time. `clock.source` moved in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
    [main.cpp]
2026-09-11 Survive having no network, and stop drawing a clock nobody set
    Four things, all about a head that boots somewhere without WiFi.
    The splash now runs before the network rather than after it. Connecting
    could take three and a half minutes with nothing reachable, and the panels
    were dark for all of it, which looks broken rather than busy.
    The setup portal is a minute instead of three, and counts down on the panels
    while it waits. That meant taking it off WiFiManager's blocking mode -- in
    blocking mode it owns the CPU until it is done and the head sits on one
    static card with no sign of how long is left. It also exits the moment a
    connection appears, so a merely slow network costs seconds ra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
    [config.h, main.cpp]
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2026-09-11 Send less over HTTP, and measure properly
    Four of the responsiveness items, one of which turned out to be wrong.
    **Gzip the control page.** It is built from data/index.html now, compressed
    by tools/gen_page.py at build time and served with Content-Encoding: gzip.
    26,055 bytes become 9,364. GET / went from 554 ms to under 100, and the
    firmware got 14 KB smaller as a bonus. The page was never slow to produce --
    39 ms of the old 554 was the handler -- it was seventeen TCP segments at
    roughly one per rendered frame. Sending fewer is the only thing that helps.
    **Trim /tz.** It was sending the POSIX string for all 61 zones, which no
    client reads: a client picks a name and sends the name bac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
    [main.cpp]
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
